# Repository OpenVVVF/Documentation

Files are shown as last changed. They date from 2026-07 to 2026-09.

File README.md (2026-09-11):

# OpenVVVF Documentation

This repository is the **single source of truth** for OpenVVVF product documentation, shared hardware data, and documentation tooling.

It is organized by hardware and software domain:

- **Control Assembly**: the reusable inverter control module (user hardware manual and software manual).
- **Power Stages**: physical chassis/inverter assemblies, each with a user manual and an assembly guide (currently documented for C2 only).
- **Safety and Compliance**: HARA, compliance mappings, and standards references; includes Testing — formal test reports and validation evidence.

Hardware designs remain in [`../InverterGen5`](../InverterGen5). Firmware and host software live in the OpenVVVF/RTE repository. This repo pulls together the documentation for all of them.

## Repository layout

```text
├── Docs/          # All documentation
├── Data/          # Shared part database and pricing data
├── Tools/         # Documentation and fabrication tooling
│   ├── BOMManager/    # Generalized BOM / fabrication package manager
│   ├── DocGen/        # Document validation and static site generator
│   └── HWRelease/     # Hardware release exporter (InverterGen5 tags -> Data/Releases)
├── Config/        # Repo-level configuration (product registry)
├── README.md
└── pyproject.toml
```

## Quick start

```bash
# Install tool dependencies
pip install -e Tools/BOMManager
pip install -e Tools/DocGen

# Run tests
pytest Tools/BOMManager/tests Tools/DocGen/tests

# Validate cross-references
python -m docgen validate

# Build the static site
python -m docgen site --output-dir site
```

## Documentation map

| Area | Path |
|---|---|
| Control assembly | `Docs/Hardware/Control-Assembly/` |
| Power stages | `Docs/Hardware/Power-Stages/` |
| Safety and compliance | `Docs/Safety-and-Compliance/` |
| Testing and validation | `Docs/Safety-and-Compliance/Testing/` |
| Part database | `Data/Parts/` |

## Contributing

See [`AGENTS.md`](AGENTS.md) and [`Docs/Agents.md`](Docs/Agents.md) for conventions used by contributors and AI agents.

## Sponsors

A special thank you to our sponsors for helping make this project possible:

<p>
  <a href="https://mouser.com">Mouser Electronics</a>
  &nbsp;&nbsp;
  <a href="https://www.mitsubishielectric.com/semiconductors/powerdevices/">Mitsubishi Electric</a>
  &nbsp;&nbsp;
  <a href="https://sendcutsend.com/">SendCutSend</a>
</p>

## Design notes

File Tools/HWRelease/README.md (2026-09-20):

# HWRelease - hardware release exporter

Turns release tags in the hardware repository (`../InverterGen5`) into
versioned, per-board artifacts under `Data/Releases/`, indexed by part number
(`HW-C2-PCB-CTRL-A`, `HW-C2-PCB-CTRL-B`, …) in `Data/Releases/manifest.json`.

## Workflow

1. In `../InverterGen5`: bump the revision in the board's KiCad files
   (`(rev "B")` in the `.kicad_sch` / `.kicad_pcb`), commit, push, and create a
   GitHub release (which creates the tag). For mechanical-only changes, instead
   rename the FreeCAD part labels and `Mechanical/Fab/<part>` folders to the
   new rev suffix and tag `<chassis-short>-<rev>` (e.g. `C2-B`): a
   chassis-named tag pins the chassis release rev and scopes the export to
   that chassis, no board rev bump needed. A release family from
   `Config/Products.yaml` (`release_families`, e.g. `C2-DCDC` = Chassis2 plus
   the DC/DC module) works the same way: tag `<family>-<rev>` (e.g.
   `C2-DCDC-A`) publishes the family's chassis tree under the family's own
   short code (`Data/Releases/C2-DCDC/A/`, `CHASSIS-C2-DCDC-A`) while boards
   keep the chassis short code (shared `HW-C2-...` part numbers).
2. Here, run:

   ```sh
   make hw-update        # or: python3 Tools/HWRelease/hwrelease.py update
   ```

   The tool fetches tags, exports each tag's `Hardware/` tree to a temp dir
   (the hardware repo's working tree is never touched), reads each board's
   revision from its KiCad files, and regenerates, via `kicad-cli` (KiCad
   flatpak), the schematic PDF, BOM CSV, gerber+drill zip, DRC report, STEP
   model, and the interactive assembly HTML (iBOM). Only board revisions not
   yet in the manifest are generated; existing ones are kept as-is.

3. Commit the new `Data/Releases/` content. The revision is now part of the
   documentation repo.

## Commands

- `hwrelease update [--tag T] [--tag-pattern GLOB] [--force] [--hw-repo PATH]`
  - export missing board revisions. Defaults: all tags, repo from
  `Config/Products.yaml` (`hardware_roots`).
- `hwrelease list` - all exported boards grouped by revision.
- `hwrelease show HW-C2-PCB-CTRL-A` - artifact paths for one part number
  (works with composite mech keys like `HW-C2-CHSP-B--C2-C` too).
- `hwrelease migrate-mech` - rebuild mech manifest entries from the exported
  `Data/Releases/<chassis>/<rev>/Mech/` trees (one entry per release; bare
  part number while unique, else `<pn>--<chassis>-<rev>`). No hardware repo
  needed.
- `hwrelease build-viewer` - regenerate `Docs/Tools/PCB-Tool/pcb-tool.html` and
  `Docs/Tools/BOM-Tool/bom-tool.html` from the manifest (runs automatically
  after `update` when new revisions were exported). docgen copies
  `Data/Releases/` into the built site.

## Vendor BOMs and pricing

`update` regenerates the chassis-level vendor BOMs (Mouser, McMaster-Carr,
SendCutSend, DigiKey, assembly, PCB) with this repo's BOMManager `generate`
against the exported tag. Board and harness BOM CSVs are first exported from
the KiCad schematics so nothing is missed. Prices come from the local price
cache / vendor APIs per your BOMManager config; variant totals (base /
standard / generous) are recorded in the manifest. If BOMManager or its deps
are unavailable, the committed BOMs from the tag are copied instead (with a
warning).

## Board ordering specs (fab_spec.yaml)

If a board directory in the hardware repo contains `fab_spec.yaml` (next to
the `.kicad_pro`), it is recorded in the manifest and shown in the tools:

```yaml
options:            # settings to pick in the JLCPCB quote form
  outer_copper: 2 oz
notes:              # free-text per-board instructions
  - "2 oz outer copper required (high-current DC bus)."
```

`Boards/fab_defaults.yaml` (same schema) holds chassis-wide notes merged into
every board (e.g. serial-number barcode instructions). The PCB Tool renders
options + notes as an "Ordering specifications" section; the BOM Tool's PCBs
table shows the per-board notes in a Notes column.

## Requirements

- KiCad via flatpak (`org.kicad.KiCad`) or `kicad-cli` on PATH.
- FreeCAD via flatpak (`org.freecad.FreeCAD`), used for mechanical-part
  extraction (optional; skipped with a warning if absent).
- `InteractiveHtmlBom` in `../InverterGen5/Hardware/BOMManager/.venv` or this
  repo's `.venv` (only needed for the interactive assembly HTML; skipped with a
  warning otherwise).

## FreeCAD extraction

On `update`, each chassis's `Mechanical/*.FCStd` is opened headlessly
(`freecadcmd` flatpak). Every `PartDesign::Body` / `App::DocumentObjectGroup`
whose **label ends with the exact part number** (`HW-...`) is exported:

- `<pn>.step`: fresh STEP, overwriting the manually exported one,
- `holes.json`: cylindrical-hole diameter histogram (mm),
- `material.json`: the part's material from the model (`ShapeMaterial` card
  name, e.g. `Aluminum-6061-T6`), when assigned; omitted when the body/group
  has no material ("Default").

The extracted material is recorded in the mech manifest entry and shown in the
BOM Tool part cards (priority: `fab_spec.yaml` material, then the extracted
material, then `info.txt` Material).

Tap/countersink diameters in `fab_spec.yaml` are validated against the model's
holes and mismatches are printed as warnings. Keep model labels exact,
e.g. `HW-C2-BSP-A`, `PhaseBusBars-HW-C2-PBB-A`.

A chassis with no boards (mechanical concept only, e.g. Chassis3) is exported
too: as long as it has a `Mechanical/*.FCStd` or a `Mechanical/Fab/` dir it
gets a `CHASSIS-<short>-<rev>` entry (rev falls back to the tag name) with its
mech parts. A chassis with no vendor BOMs and no mech parts is skipped.

## Conventions

- Board → part number mapping comes from `Config/Products.yaml` (chassis short
  codes) and `Data/Parts/Descriptors.json` (`<Chassis>|pcb|<board> → PREFIX`).
  A board missing either mapping is skipped with a warning.
- Tag naming is up to the hardware repo (e.g. `hw-rev-a`); use `--tag-pattern`
  to restrict discovery.
- `Data/Releases/` is committed generated data: do not hand-edit; regenerate
  with `--force` instead.
- **KiCad DNP grouping quirk**: KiCad marks an entire BOM `--group-by` row as
  DNP if any symbol in the group is DNP, so `export_bom` groups by
  `Value,DNP` (not `Value` alone) to keep populated rows separate. Do not
  "simplify" this back; after changing the BOM export, regenerate
  `Data/Releases/` with `hwrelease update --force`.
- **InteractiveHtmlBom DNP quirk**: CLI generation must export a KiCad XML
  netlist from the schematic, pass it through `--extra-data-file`, and select
  `--dnp-field kicad_dnp`. Without both iBOM options, DNP footprints are
  presented as ordinary placement rows and the viewer's "DNP outlined" toggle
  does nothing. The schematic is deliberately used as the same source of truth
  as the purchasing BOM; PCB DNP attributes can be stale. PCB fields are only
  used as a fallback for a board that has no matching schematic. Keep the
  regression tests in `tests/test_kicad.py` when changing the iBOM command.

## Tests

```sh
make test-hwrelease
```

## Roadmap / planned

- **Ordering screenshots per board and per part**: the user will capture
  screenshots of the JLCPCB / SendCutSend ordering flows. Convention (TBD):
  images alongside `FabSpec.md` per board (PCB Tool) and per mechanical part
  (BOM Tool / part explorer), exported into `Data/Releases/` and shown in the
  tools so ordering settings are unambiguous.
- **Mechanical parts explorer**: auto-discover mechanical parts (SendCutSend
  sheet parts, McMaster hardware) from the hardware repo at export time and
  give them their own tool page, like the PCB Tool: renders/screenshots,
  specs, vendor links, prices.

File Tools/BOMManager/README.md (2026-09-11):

# BOM Manager

Your fab-time companion for the inverter build. It aggregates the Bill of
Materials from KiCad PCB exports, wiring-harness schematics, mechanical
hardware, and custom fabricated parts, then helps you price everything,
order the right quantities (including pack sizes and what is already on your
shelf), and keep fabrication packages ready to send out.

## The interactive shell

```bash
cd Tools/BOMManager
python3 bom.py
```

```
bom> status                     # where you stand: lines, prices, attention items, fab readiness
bom> mech                       # the MechanicalBOM.txt hardware list (the tool owns this file)
bom> mech add McMaster 94669A199 12 M3x10 SHCS
bom> price 94669A199 3.10       # set a price (per piece, or per pack if packed)
bom> pack 94669A199 25          # sold in boxes of 25 -> ordering does the math
bom> stock 94669A199 19         # 19 left over on your shelf (stays local, never committed)
bom> add                        # walk through BOM lines that still need vendor PNs/prices
bom> new fab Phase Bus Bar      # scaffold a fabricated-part folder (+README)
bom> new harness GateDriverHarness
bom> new board PowerBoard
bom> rev bump DCLBB --note "widen holes"
bom> fab                        # fabrication package readiness: PCBs, fab parts, harnesses
bom> import mouser              # paste a cart/order, prices land in cache AND the committed DB
bom> import digikey ~/Downloads/digikey_bom.csv.xlsx
bom> release                    # order files + full PDF report (schematics, layers, pricing)
```

Every command also works one-shot for scripting: `python3 bom.py generate --qty 5`.
Type `help` inside the shell for the full list. **See `Docs/GUIDE.md` for the
complete usage guide.**

The old scripts (`generate_bom.py`, `manage_parts.py`, `import_*.py`) still run
; they are thin shims that delegate to the shell.

## What `generate` and `release` produce

Per chassis, under `Hardware/<Chassis>/FabricationData/`:

```text
├── BOMs/
│   ├── Consolidated_BOM.csv     # everything, with Order Qty / Pack Size / Leftover columns
│   ├── mouser_bom.csv           # upload to the vendor's BOM tool
│   ├── digikey_bom.csv
│   ├── mcmaster_bom.csv
│   ├── sendcutsend_bom.csv
│   ├── pcb_bom.csv
│   └── assembly_bom.csv         # in-house assemblies (wiring harnesses)
├── McMaster_Order_Paste.txt     # paste straight into the McMaster cart
├── PCB_Fab_Zips/<Board>.zip     # per-board fab bundles
├── Assembly/<Board>.html        # interactive assembly view per board (iBOM; via release)
├── Pricing_Report.md            # costs, pack rounding, fabrication package checklist
├── Subassembly_Pricing.json     # per-subassembly totals + lines (cost of ordering each alone; also in Builds/ and BOMs/Variants/ outputs)
├── Release_Report.pdf           # full release doc (HARA-style; via release): cover, pricing,
│                                # STEP previews, per-board 3D renders + schematic + layers
├── Builds/<variant>/            # build-variant outputs, when variants.yaml declares them
│                                # (same file set as above; the default variant stays at this root)
├── Variant_Comparison.md        # per-variant totals + part deltas (tracked)
└── variants.json                # machine-readable variant manifest (tracked)
```

Chassis with a `variants.yaml` (e.g. Chassis2's 200v/450v builds) generate all
declared build variants at once; `generate --variant 450v` builds a subset. See
[Docs/GUIDE.md](Docs/GUIDE.md#build-variants) for the schema.

## How ordering math works

- A part with `pack_size = 25` and 6 needed → order **1 pack**, 19 left over.
- `stock` counts are subtracted first: 6 needed, 19 on hand → order 0.
- Order quantities (packs) are what land in vendor CSVs and the McMaster paste
  file; lines fully covered by stock are skipped there but still shown in the
  Consolidated BOM and the report's **Pack Rounding & Stock** section.
- Prices are per **order unit**: per piece normally, per pack when packed.

## Where data lives

Committed (project data, diff-friendly):

| File | Contents |
|---|---|
| `Data/Parts/Database.json` | vendor PNs, pack sizes, manual prices, notes |
| `Data/Parts/Numbers.json` | internal PN registry with revision history |
| `Data/Parts/Descriptors.json` | short names used in part numbers |
| `Hardware/<Chassis>/Mechanical/MechanicalBOM.txt` | purchased hardware list (edit via `mech` commands) |
| `Hardware/<Chassis>/Mechanical/Fab/<Part>/` | fabricated parts: STEP + `info.txt` + image |
| `Hardware/<Chassis>/Wiring/<Name>/` | wiring harnesses: KiCad schematic + BOM CSV export |

Local only (gitignored): `Config.yaml` (API keys), `PriceCache.json`,
`Inventory.json` (your on-hand stock; your leftover screws are not project data).

## Part numbers and revisions

Every BOM line gets an internal PN like `HW-C2-BB-DCLBB-A`
(chassis, category, descriptor, revision). Registry keys are **identity-based**,
so editing a description or friendly part name never renumbers anything, and
folder names never need to change for a revision:

```text
bom> rev list
bom> rev bump DCLBB --note "widen mounting holes"
```

For fabricated parts this writes `Rev=B` into the part's `info.txt`; the
folder and STEP file stay put, so CAD and vendor links keep working.

## First-time setup

```bash
pip install -r requirements.txt        # runtime deps
pip install -r requirements-dev.txt    # + pytest, for the test suite
python3 -m pytest tests/               # sanity check
cp Config.yaml.example Config.yaml     # optional: vendor API keys (Docs/API_KEYS.md)
```

API keys are optional: the whole workflow runs on manual prices and pasted
cart/order imports.

## Docs

- `Docs/GUIDE.md`: **complete usage guide (start here)**
- `Docs/WORKFLOW.md`: end-to-end fab-time walkthrough
- `Docs/CUSTOM_PARTS.md`: fabricated parts and SendCutSend
- `Docs/PART_NUMBERING.md`: internal PN conventions and revisions
- `Docs/API_KEYS.md`: optional vendor API setup
- `Docs/SPARES_AND_REPORTING.md`: spares policies and report format

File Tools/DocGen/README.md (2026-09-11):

# docgen

OpenVVVF documentation validation and static site generator.

## Commands

```bash
# List all doc_ids
python -m docgen index

# Validate cross-references
python -m docgen validate

# Build the static HTML site
python -m docgen site --output-dir site

# Assemble a document set into a single Markdown file (legacy product-manual mode)
python -m docgen build --product <product_id> --output <file.md>

# Generate clean PDFs from the built site (run `site` first; uses headless Chromium)
python -m docgen pdf --all                    # one PDF per document
python -m docgen pdf --doc OV-C2-UM-INDEX     # a single document
python -m docgen pdf --manual OV-C2-AG-INDEX  # umbrella PDF: index document plus its chapters
python -m docgen pdf --all --chromium /path/to/chrome   # explicit Chromium/Chrome binary
```

## Document structure

Documents live under `Docs/` as `Index.md` files inside kebab-case folders. Ordered assembly chapters/steps use a `<N>_<kebab-case-title>` naming convention; the site generator renders dashes as spaces and title-cases the result.

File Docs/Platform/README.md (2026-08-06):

---
doctype: Index
doc_id: OV-PLATFORM-INDEX
title: OpenVVVF Platform Documentation
product_line: openvvvf
applies_to:
  - openvvvf-control-module
version: "0.1"
prepared: Thomas Liao
reviewed: (not yet reviewed)
date: "2026-07-30"
status: draft
---

# Platform Documentation

The control module is the reusable, application-independent part of OpenVVVF.
Documentation here applies to all power stages and application profiles.

- `Safety/` — HARA, TARA, FMEA
- `Compliance/` — Standards mapping (ISO 26262, IEC 61800-5-2, EN 5012x)
- `Architecture.md` — System architecture overview

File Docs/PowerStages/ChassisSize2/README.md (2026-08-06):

---
doctype: Index
doc_id: OV-CHASSIS-C2-INDEX
title: OpenVVVF Chassis Size 2
product_line: openvvvf
applies_to:
  - chassis-size-2
version: "0.1"
prepared: Thomas Liao
reviewed: (not yet reviewed)
date: "2026-07-30"
status: draft
normative_refs:
  - OV-UM-C2
---

# Chassis Size 2

140 V nominal / 600 A build.

- `UserManual.md` — Assembly and operating manual
- `Assembly/PowerStage/IGBTMounting.md` — IGBT module mounting procedure
- `ThermalAnalysis.md` — System thermal analysis
- `DCLinkThermal.md` — DC link standoff heat-path analysis
- `FabricationGuide.md` — Fabrication and build notes

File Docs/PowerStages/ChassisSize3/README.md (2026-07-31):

---
doctype: Index
doc_id: OV-CHASSIS-C3-INDEX
title: OpenVVVF Chassis Size 3
product_line: openvvvf
applies_to:
  - chassis-size-3
version: "0.1"
prepared: Thomas Liao
reviewed: (not yet reviewed)
date: "2026-07-30"
status: draft
---

# Chassis Size 3

Up to 1200 V / 1400 A. In development.

*Documentation will be added as the design matures.*

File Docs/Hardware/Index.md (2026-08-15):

---
doctype: Index
doc_id: OV-HW-INDEX
title: Hardware
product_line: openvvvf
applies_to:
  - openvvvf-control-module
  - chassis-size-2
version: "0.1"
date: "2026-08-08"
description: OpenVVVF hardware documentation - control module and power-stage chassis.
nav_order: 10
normative_refs:
  - OV-DOCS-INDEX
---

# Hardware

OpenVVVF hardware is split into two parts: the reusable control module and the power-stage chassis that it drives.

- [Control Assembly](Control-Assembly/Index.md) - the dual-MCU control board that runs the firmware.
- [Power Stages](Power-Stages/Index.md) - the physical inverter chassis (currently C2).

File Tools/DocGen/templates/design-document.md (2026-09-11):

---
# Template for a design analysis / calculation document.
# Place under Docs/Hardware/Power-Stages/C2/Design-Documents/<Topic>/
doctype: Design Document
doc_id: OV-C2-DD-XXXX
title: Topic Analysis
product_line: openvvvf
applies_to:
  - chassis-size-2
version: "0.1"
date: "YYYY-MM-DD"
status: draft
description: One-sentence summary of the analysis.
nav_order: 33N
normative_refs:
  - OV-C2-DD-INDEX
---

# Topic Analysis

## Purpose and scope

What question does this document answer? What is in and out of scope?

## Assumptions

- ...

## Methodology

## Calculations

## Results

## Recommendations

## References

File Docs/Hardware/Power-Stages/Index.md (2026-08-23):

---
doctype: Index
doc_id: OV-PS-INDEX
title: Power Stages
product_line: openvvvf
applies_to:
  - chassis-size-2
version: "0.4"
date: "2026-08-23"
description: Physical chassis and inverter assemblies. Each chassis family has an integration guide and an assembly guide.
nav_order: 200
---

# Power Stages

OpenVVVF power stages are physical chassis/inverter assemblies that pair with the control module. Each chassis is a family of variants built around a common form factor and IGBT module choice; the same control module can drive any of them.

## Which chassis do I have?

| Chassis | Form factor | Typical DC link | Current rating (peak phase current) | Status |
|---|---|---|---|---|
| **[C2 - Chassis Size 2](C2/Index.md)** | Mid-size | 150 / 200 / 400 V class, per DC-link capacitor selection | **465 A continuous / 600 A peak (60 s)** | Implemented, under test |

C2 ratings are stated in peak phase current (RMS equivalents: 330 A continuous, 424 A peak) per the IEC 61800-2 style 60 s overload convention: the 600 A peak is time-limited (60 s per event, windowed RMS over any 10 min ≤ 330 A RMS), and the 465 A continuous figure is a conservative analytical bound set by the DC-link electrolytic ripple rating at 6 kHz PWM. The DC-link plate temperature is an informational bound after the rev-B 6.35 mm spreader plate (≈ 90 °C conservative bound at the continuous point, at the FSR-08 90 °C derate onset; the model credits no convection). See `OV-C2-DD-THERMAL` (§6.4), `OV-C2-DD-DCLINK-RIPPLE`, and `OV-C2-DD-DCLINK-THERMAL`.

- If you are building or installing a C2 unit, start with the [C2 Integration Guide](C2/Integration-Guide/Index.md) or [C2 Assembly Guide](C2/Assembly-Guide/Index.md).

## Revision History

| Version | Date | Changes |
|---|---|---|
| 0.2 | 2026-08-15 | (Prior revision; see git history.) |
| 0.3 | 2026-08-20 | C2 current rating restated as 220 A continuous / 600 A peak (60 s, IEC 61800-2 style overload convention), replacing the previous "~600 A continuous" advertisement; continuous rating is a conservative analytical bound set by the DC-link plate temperature at 6 kHz PWM, below the ~320 A electrolytic ripple limit. References to the C2 design docs added. |
| 0.4 | 2026-08-23 | C2 re-rated per `OV-C2-DD-THERMAL` v1.3: the 600 A figure is peak phase current (424 A RMS), and the continuous rating is raised to 465 A (330 A RMS), now set by the electrolytic ripple limit; the rev-B 6.35 mm DC-link spreader plate moved the plate temperature to an informational bound below the FSR-08 derate onset. Ratings stated in peak phase current with RMS equivalents noted. |

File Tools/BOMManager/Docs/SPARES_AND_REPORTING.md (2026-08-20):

# Spares Policies and Price Reporting

## Spares Policies

Controlled by `--spares`:

| Policy | Behavior |
|---|---|
| `none` | Exact BOM quantity. |
| `cheap` | Round resistors, capacitors, and mechanical fasteners to standard pack sizes (10, 25, 50, 100, 200, 500, 1000). |
| `all` | Add `--spares-pct` percent to every line (default 10%). |

Examples:

```bash
python3 bom.py generate --spares cheap
python3 bom.py generate --spares all --spares-pct 20
```

Spares are applied to the *needed* quantity before pack-size rounding, so a
line needing 8 screws at pack size 25 with `--spares cheap` orders 1 pack
(need rounds to 10, then to 1 box of 25).

## Price Report

`Hardware/Chassis2/FabricationData/Pricing_Report.md` is regenerated on every run and contains:

- One section per vendor with line items, order info, unit price, line total, and price source.
- Vendor subtotals.
- Grand total for the requested quantity.
- A quantity-scaling table (default 3, 5, 10, 25 units).
- A **Pack Rounding & Stock** section: need vs. on-hand vs. packs ordered vs. leftover.
- A **Fabrication Package** checklist: per-board fab files/zip/price, per-part STEP/info/price/rev, harness CSVs, and anything not ready.
- A list of parts with unknown/missing prices.
- A SendCutSend details section with material, thickness, finish, STEP path, and embedded `info.png` images.

The report is Markdown so it renders nicely in GitHub/GitLab and can be committed to track project cost over time. Each chassis gets its own report under `Hardware/<Chassis>/FabricationData/`.

## Quantity Scaling

Use `--qty N` to scale the whole BOM:

```bash
python3 bom.py generate --qty 5
```

The consolidated CSV quantities are multiplied by N (order quantities are
computed from the scaled need), and the report grand total reflects N units.
You can change the scaling table with `--extra-qtys`:

```bash
python3 bom.py generate --qty 1 --extra-qtys 2,5,10,25,50
```

## Price Sources

Each line shows where the price came from:

- `mouser_api`, `digikey_api`, `octopart_api`: live lookup (needs API keys).
- `mouser_cart_import`, `mcmaster_order_import`, `jlcpcb_order_import`: pasted cart/order imports.
- `sendcutsend_folder`: the part's `info.txt`.
- `manual`: set by hand in the shell (`price`, `pack`, `fab pcb-price`).
- `cache`: from `PriceCache.json`.
- `unknown`: no price found; listed in the report for follow-up.

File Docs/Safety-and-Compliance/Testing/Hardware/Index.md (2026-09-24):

---
doctype: Index
doc_id: OV-TEST-HW-INDEX
title: Hardware Tests
product_line: openvvvf
applies_to:
  - openvvvf-control-module
  - chassis-size-2
version: "0.4"
date: "2026-09-24"
description: Hardware test reports and validation evidence.
nav_order: 341
---

# Hardware Tests

Electrical, thermal, mechanical, and environmental test records.

## PMSM motor

- [PMSM Resistance Calibration Validation](PMSM-Motor-Calibration/Resistance/Index.md)
- [Power Resistor Sanity Check](PMSM-Motor-Calibration/Resistor-Sanity-Check/Index.md)
- [PMSM Inductance Calibration Validation](PMSM-Motor-Calibration/Inductance/Index.md)

## Induction motor

- [Induction Motor Testbed](Induction-Motor-Calibration/Testbed/Index.md)
- [Induction Motor Resistance Calibration Validation](Induction-Motor-Calibration/Resistance/Index.md)
- [Inductance Calibration Validation](Induction-Motor-Calibration/Inductance/Index.md)
- [Induction Motor 1-Hour No-Load Test](Induction-Motor-No-Load-Test/Index.md)
- [Induction Motor 180 V Power Stage Bring-up](Induction-Motor-180V-Bringup/Index.md)
- [Induction Motor 180 V 20-Minute Reversal Test](Induction-Motor-180V-Reversal/Index.md)

## Gen7 hardware

- [Gen7 Board Temperature Sensor Validation](Gen7-Temp-Sensor-Validation/Index.md) - first Gen7 test record; validates the three board NTC temperature channels against a thermal imager under a torch-applied gradient.
- [Low-Power Regen 100 A Phase-Current Endurance (No Cooling)](Low-Power-Regen-100A-No-Cooling/Index.md) - 22-minute continuous regen at −100 A q-axis current on a dynamometer-spun induction machine with the bare power stage (no heatsink, no fan); peak board temp 80.4 °C.
- [200 A Regen to 79 °C — Gen7 Size 2](Low-Power-Regen-200A-Gen7-Size2/Index.md) - 200 A q-axis regen staircase on Gen7 size 2, 3.14 kW average returned to the DC link, split at the first 79 °C inverter NTC reading; heatsink fitted without thermal interface material.
- [Thermal OTP Trip — 200 A Regen, Gen7 Size 2](Thermal-OTP-200A-Gen7-Size2/Index.md) - continuation of the same recording past 79 °C through the intended thermal over-temperature protection trip and cooldown.
- [Initial 400 A Regen Test — Gen7 Size 2](Low-Power-Regen-400A-Gen7-Size2/Index.md) - first 400 A q-axis regen run with a Chroma load bank clamping the bus at 150 V (Sorensen regen sink ~50 A); 8.78 kW peak; apparent phase-current spikes later attributed to 150 A-rated Tektronix current clamps saturating (measurement artifact).
- [450 A / 13 kW Regen — Gen7 Size 2](Low-Power-Regen-450A-Gen7-Size2/Index.md) - 450 A q-axis regen at 2,000 RPM shaft speed, 12.8 kW average returned to the DC link, sustained 78 s until the inverter overtemperature protection tripped at ~80 °C baseplate as designed.
- [200 A Regen Steady-State Thermal Test — Gen7 Size 2](Low-Power-Regen-200A-Steady-State-Gen7-Size2/Index.md) - 54.7-minute continuous 200 A regen on the thermally-pasted assembly; baseplate plateaued at 44.4 / 44.0 °C against 22.5 °C ambient, validating the interface rework.
- [200 A Motoring Steady-State Thermal Test — Gen7 Size 2](Low-Power-Motoring-200A-Steady-State-Gen7-Size2/Index.md) - motoring-direction counterpart: 42-minute 200 A positive-torque hold drawing 2.46 kW, baseplate plateau 43.6 / 43.5 °C in cooler night ambient — same rise over ambient as regen, completing bidirectional 200 A continuous-duty validation.
- [300 A Regen Steady-State Thermal Test — Gen7 Size 2](Low-Power-Regen-300A-Steady-State-Gen7-Size2/Index.md) - 22.9-minute continuous 300 A regen at ~2,600 RPM returning 11.7 kW to a 150 V-clamped bus; baseplate reached effective steady state at 63.2 / 61.7 °C (~39 K over ambient). Stopped because the Zero ZF75-10 machine hit 86 °C on the thermal imager, not due to any inverter limit or fault.

## Cross-cutting

- [Motor Self-Commissioning Accuracy Report](Motor-Self-Commissioning-Accuracy/Index.md) - aggregates the calibration-validation measurements into a single accuracy record for the self-commissioning routine.

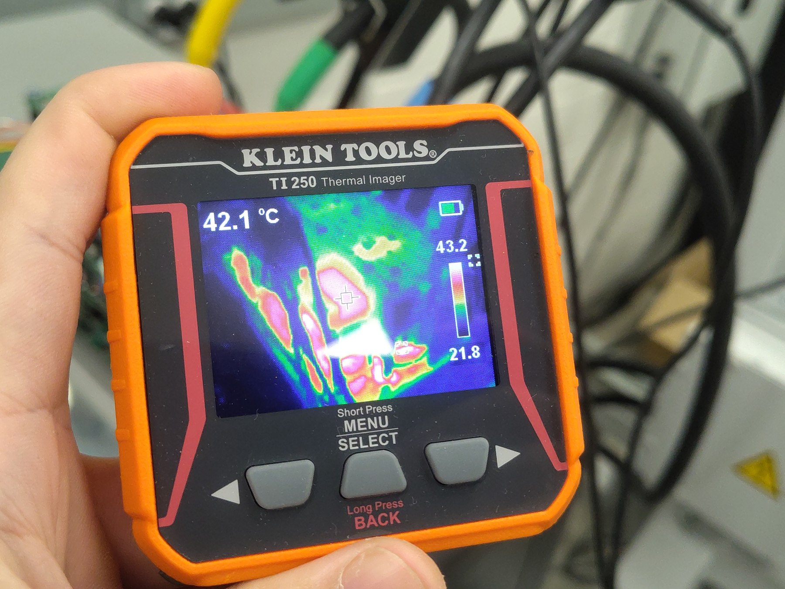
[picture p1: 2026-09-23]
Docs/Safety-and-Compliance/Testing/Hardware/Low-Power-Regen-200A-Gen7-Size2/Thermal-01.jpg

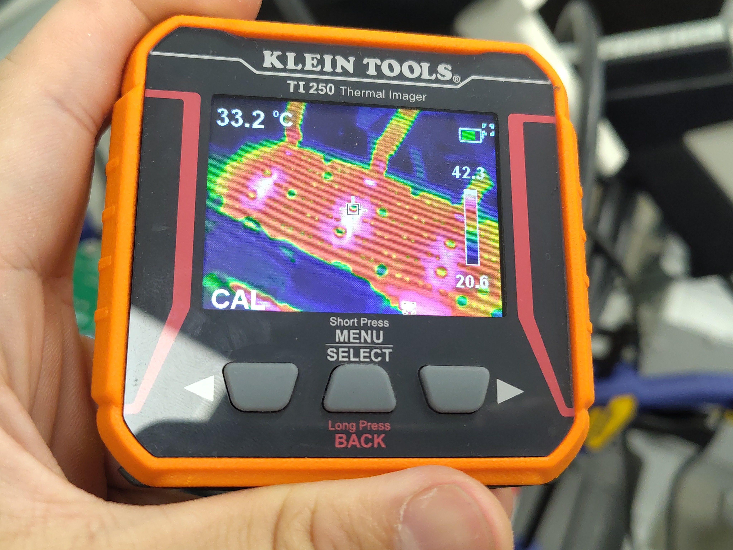
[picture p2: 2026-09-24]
Docs/Safety-and-Compliance/Testing/Hardware/Low-Power-Motoring-200A-Steady-State-Gen7-Size2/Thermal-02-Original.jpg

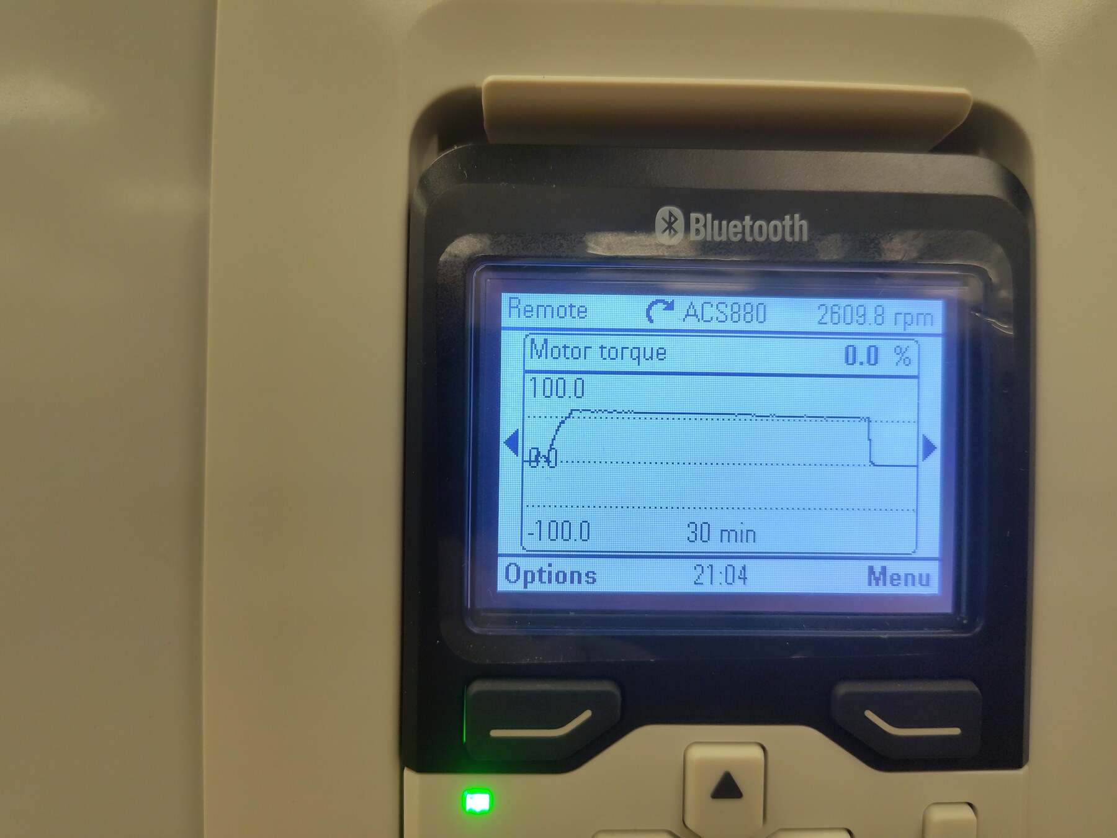
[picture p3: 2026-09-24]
Docs/Safety-and-Compliance/Testing/Hardware/Low-Power-Regen-300A-Steady-State-Gen7-Size2/Dyno-Display.jpg

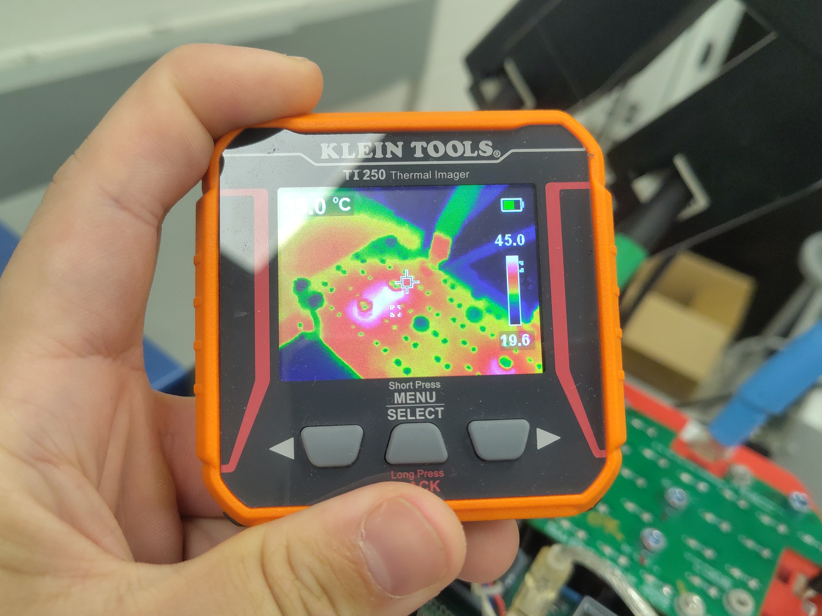
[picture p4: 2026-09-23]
Docs/Safety-and-Compliance/Testing/Hardware/Low-Power-Regen-200A-Gen7-Size2/Thermal-04-Original.jpg

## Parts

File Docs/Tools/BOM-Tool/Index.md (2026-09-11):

---
doctype: Tool Manual
doc_id: OV-TOOLS-BOM-TOOL
title: BOM Tool
product_line: openvvvf
applies_to:
  - openvvvf-control-module
  - chassis-size-2
version: "0.4"
date: "2026-09-10"
description: Vendor order BOMs (Mouser, McMaster-Carr, SendCutSend, PCB, 3D Printed; DigiKey when data exists) per chassis, revision, and build variant.
nav_order: 603
normative_refs:
  - OV-TOOLS-INDEX
---

# BOM Tool

The BOM Tool serves the per-chassis vendor order BOMs exported from the hardware repository's release tags. Select a chassis, revision, and build variant, then preview or download the vendor BOM you need.

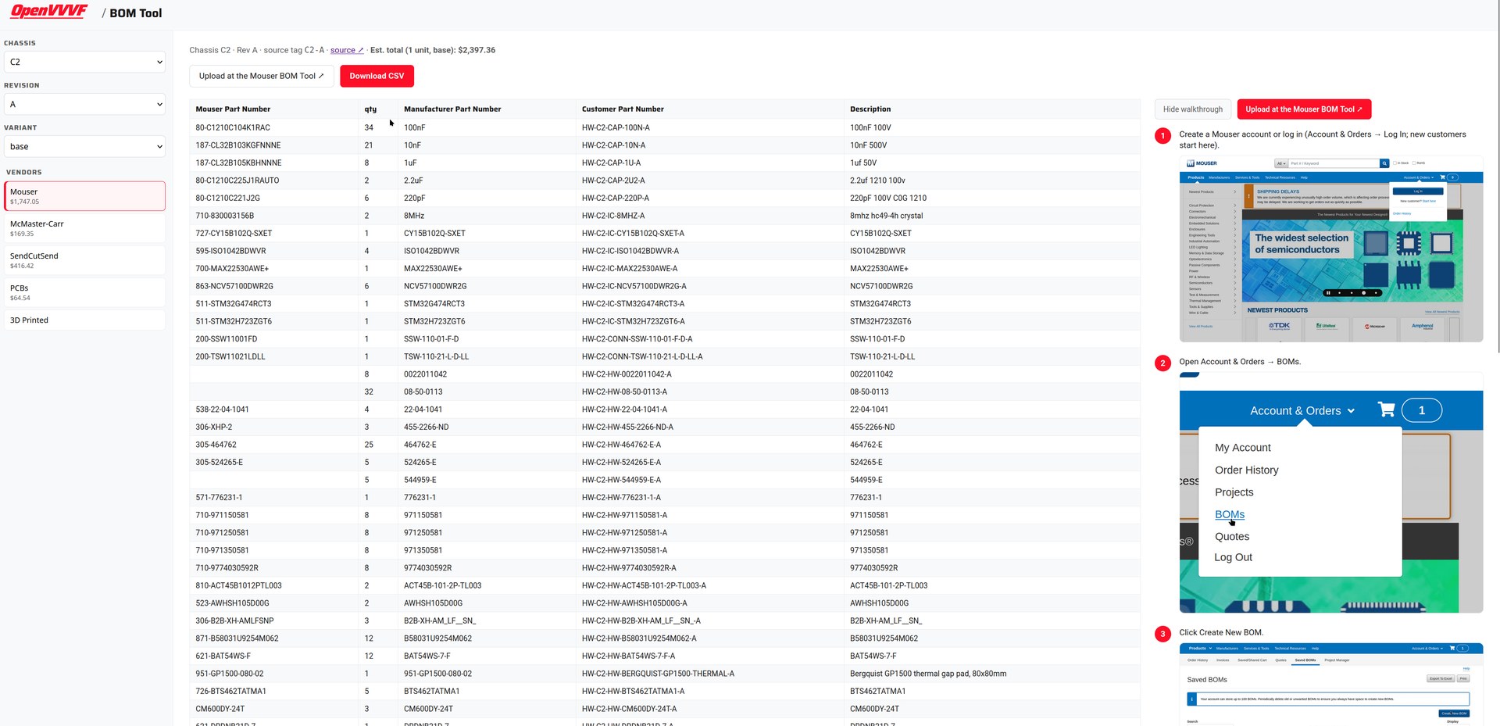
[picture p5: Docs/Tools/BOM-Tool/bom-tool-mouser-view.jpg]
BOM Tool showing the Mouser order BOM with the ordering walkthrough


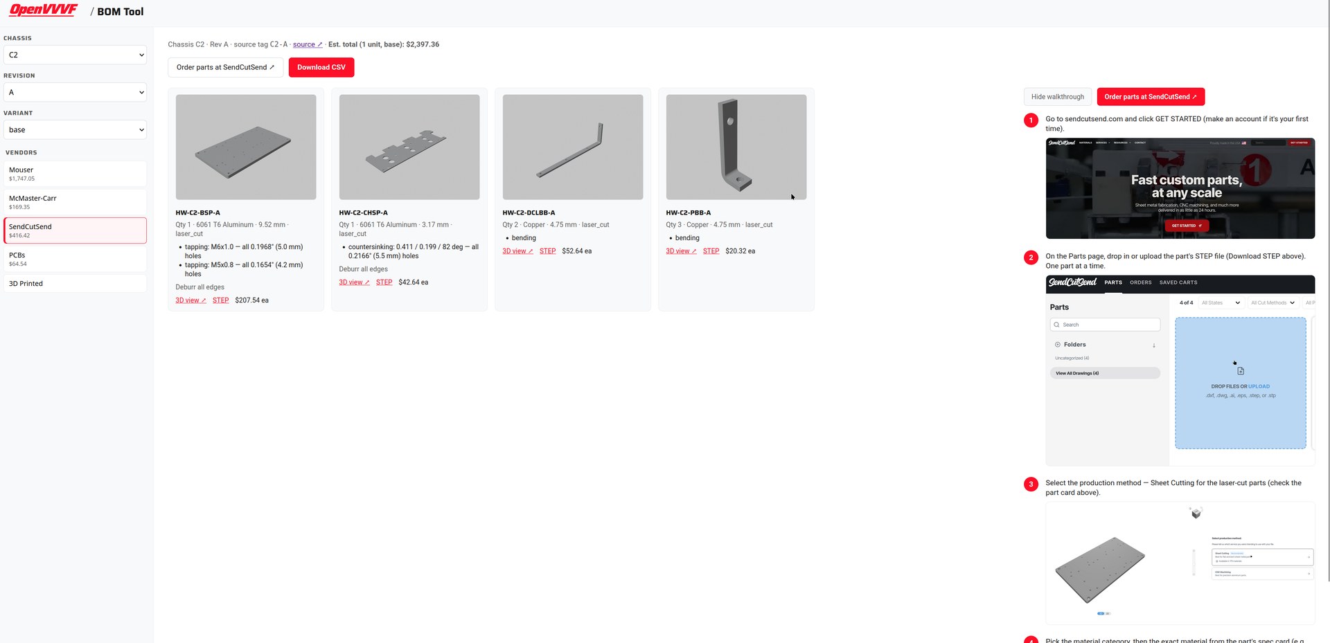
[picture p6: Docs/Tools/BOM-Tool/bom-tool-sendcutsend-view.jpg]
BOM Tool showing fabricated parts with 3D previews and SendCutSend ordering


## Using the tool

1. Open the [BOM Tool](bom-tool.html).
2. Choose the **chassis**, **revision**, and **variant** (`base` is the standard build; named variants such as `generous` come from the hardware repo's BOM variants).
3. Click a vendor button (**Mouser**, **McMaster-Carr**, **SendCutSend**, **PCBs** (JLCPCB fab), **3D Printed** (printed parts); a **DigiKey** button appears only when DigiKey data exists for that release) to preview the BOM inline. Vendor buttons show their share of the cost estimate. The consolidated and assembly (in-house harnesses) BOMs have no buttons; download their CSVs from the release's `BOMs/` directory.
4. Order with as few clicks as vendors allow. For the selected chassis+revision the actions row may show **ready-made shared carts** ("Open ready-made Mouser/SendCutSend cart", "Open shared DigiKey list" — buy as-is). For Mouser, **Copy order list** copies `Mouser PN<tab>qty` lines and opens the BOM import; paste there (Account & Orders → Import). For McMaster-Carr, **Copy order paste** copies `PN,qty` lines for the order pad, and **Open McMaster-Carr order page** jumps straight to it. The subassembly view (step 5) has equivalent copy buttons limited to that subassembly's lines; entries without a vendor part number are skipped.
5. To price one part of the inverter on its own (e.g. just the control board or the wiring harnesses), pick it in the **Subassembly** selector between the variant selector and the vendor buttons. The preview then shows that subassembly's lines with per-vendor subtotals instead of a vendor table. These totals assume you order *only* that subassembly — pack sizes are rounded up separately per subassembly, so the subassemblies can add up to more than the whole-BOM estimate. Clicking a vendor returns to the whole-BOM view. Releases exported before this feature have no per-subassembly data yet; the selector shows a disabled "All (no per-subassembly data yet)" entry until the next `hwrelease update`.
6. Use **Download CSV** to save it for ordering (e.g. pasting into the vendor's BOM import). For boards, **View boards in PCB Tool** takes you to the per-board gerbers/specs, and **Order PCBs at JLCPCB** opens the fab.

### Ordering walkthrough screenshots

When a vendor is selected, the tool shows a step-by-step walkthrough of that vendor's upload/ordering flow below the buttons (for McMaster-Carr there's also a button that copies the order paste to the clipboard). The walkthrough is hand-maintained: drop files next to this document named `ordering-<vendor>-<n>.png` (screenshot) and `ordering-<vendor>-<n>.txt` (one-line caption), numbered in order (`n` = 1, 2, …; vendors: `mouser`, `digikey`, `mcmaster`, `sendcutsend`, `jlc`). Either file may exist alone: steps without a screenshot show as text only. No regeneration is needed; they are picked up on the next site build.

The estimate in the header reflects the selected variant (`base`, `standard`, `generous`).

### Registering ready-made shared carts (maintainer)

None of the vendors offer anonymous cart URLs, so shared carts are created once by the maintainer in their vendor account and registered in `shared-carts.json`, a hand-edited file next to this page (it is not generated; `hwrelease build-viewer` never touches it):

```json
{ "C2": { "C": { "mouser": "https://...", "sendcutsend": "https://...", "digikey": "https://..." } } }
```

Keys are `"<chassis-short>"` → `"<rev>"` → vendor → URL; vendors without an entry simply show no button, and a missing `shared-carts.json` is fine.

- **Mouser**: build the BOM in a My Mouser project (Project Manager), use Share, and copy the `ProjectDetail.aspx?AccessID=…` link. Visitors open it and click "Order Project" — this keeps project ownership/annotations with the maintainer.
- **SendCutSend**: load a saved cart, use the cart's share link (`https://cart.sendcutsend.com/<id>`). Caveats: links expire after ~30 days (or on cart/account changes), and CNC-machined parts can't be shared.
- **DigiKey**: share a list from the DigiKey lists page. (Not currently used — this project's BOMs carry almost no DigiKey part numbers.)

## Where the data comes from

The CSVs are regenerated from the tag's KiCad sources on every export: HWRelease (`make hw-update`) runs BOMManager's `generate` (with pricing) against the exported tag tree, so they can never go stale. They live in `Data/Releases/<chassis>/<rev>/BOMs/` and are indexed in `Data/Releases/manifest.json` under `CHASSIS-<chassis>-<rev>` entries. The page itself is regenerated with `hwrelease build-viewer` (runs automatically after `update`).

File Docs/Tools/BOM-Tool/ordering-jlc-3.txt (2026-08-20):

JLCPCB auto-detects the layers and dimensions. Set the remaining options from the board's ordering specs (Notes column / PCB Tool), e.g. 2 oz copper for DCBusCapacitorBoard.

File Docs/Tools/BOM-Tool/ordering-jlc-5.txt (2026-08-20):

Always: select 2D barcode Only, size 10*10mm, choose Specify Position, then Submit. Never leave the position up to the fab.

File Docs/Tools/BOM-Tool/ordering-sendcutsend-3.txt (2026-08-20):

Select the production method: Sheet Cutting for the laser-cut parts (check the part card above).

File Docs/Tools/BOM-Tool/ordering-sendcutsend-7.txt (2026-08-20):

For Tapping: SendCutSend lists every hole diameter: select the thread from the part's fab spec for each diameter that needs it, leave the rest unselected.

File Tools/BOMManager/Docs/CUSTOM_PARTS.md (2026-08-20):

# Custom Parts (McMaster-Carr and SendCutSend)

## McMaster-Carr Parts

McMaster-Carr has an approved-customer Product Information API (see
`API_KEYS.md`). If you configure the certificate-based credentials, the tool
uses the official API; otherwise it falls back to cached or manually set
prices.

### The mechanical list

`Hardware/<Chassis>/Mechanical/MechanicalBOM.txt` is owned by the tool; add
and change rows from the shell instead of editing by hand:

```text
bom> mech                                   # list with prices
bom> mech add McMaster 94669A199 12 M3x10 SHCS
bom> mech set 94669A199 20
bom> mech rm 94669A199
```

The file stays a plain CSV (`Qty,Vendor,PN,Description`), sorted and
deduplicated on every change. Any vendor string works (`McMaster`, `Digikey`,
`Mitsubishi`, ...). Set prices with `price <pn> <usd>`, and if the part comes
in a box, `pack <pn> 25 <box price>`; ordering then counts packs, not pieces.

## SendCutSend Fabricated Parts

Bus bars, plates, brackets, and other laser/waterjet-cut parts live one folder
per part under `Hardware/<Chassis>/Mechanical/Fab/<PartName>/`. Scaffold a new
one from the shell:

```text
bom> new fab DC Link Bus Bar
```

which creates:

```text
Hardware/<Chassis>/Mechanical/Fab/HW-C2-DCLBB-A/
├── info.txt        # specs and price (template)
└── README.md       # what goes here
```

Drop in `<folder>.step` (required) and `info.png` (optional, embedded in the
price report).

### `info.txt` fields

```ini
PartName=DC Link Bus Bar
Material=Copper
Thickness_mm=4.75
Qty=2
Dimensions_in=12.357x0.551 in
Finish=Bending
UnitPrice=50.71
Process=Sheet Cutting
Notes=Tin plate ends after forming
```

| Field | Description |
|---|---|
| PartName | Human-readable name. Words like "bus bar", "plate", "bracket" drive category detection. |
| Material | e.g., `Copper`, `5052 aluminum` |
| Thickness_mm | Sheet thickness in mm |
| Qty | Quantity per chassis |
| Dimensions_in or Dimensions_mm | Part dimensions |
| Finish | e.g., `as cut`, `Bending`, `tinned`, `anodized` |
| UnitPrice | USD per part |
| Process | e.g., `Sheet Cutting` |
| Notes | Design notes, tolerances, etc. |
| Rev | Managed by the tool (`rev bump`); do not edit by hand. |

Each part gets an internal part number such as `HW-C2-BB-DCLBB-A`
(see `PART_NUMBERING.md`).

### Importing from a SendCutSend cart

After building a cart on SendCutSend, copy the page text and paste it:

```text
bom> import sendcutsend            # paste, then Ctrl+D
bom> import sendcutsend cart.txt   # or from a file
bom> import sendcutsend cart.txt --dry-run
```

The importer matches cart filenames to existing folders regardless of token
order (`C2_HW_BSP_A.step` matches `HW-C2-BSP-A`), creates missing folders, and
writes/updates each `info.txt`, including the quoted price.

### Revisions

`rev bump DCLBB --note "..."` bumps the revision and writes `Rev=` into
`info.txt`. Folders and STEP files are never renamed, so vendor re-uploads and
CAD links keep working.

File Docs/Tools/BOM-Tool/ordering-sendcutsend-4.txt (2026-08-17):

Pick the material category, then the exact material from the part's spec card (e.g. Copper, 6061 T6 Aluminum).

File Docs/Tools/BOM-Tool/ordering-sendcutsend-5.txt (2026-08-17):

Pick the thickness from the part's spec card (e.g. .187" / 4.7 mm for the bus bars).

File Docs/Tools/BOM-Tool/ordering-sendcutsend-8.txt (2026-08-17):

Same for Countersinking: pick the feature per hole diameter per the spec, then review the quote and add to cart. Repeat for each part.

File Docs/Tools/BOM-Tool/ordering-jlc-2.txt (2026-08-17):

Click Add gerber file and upload the board's gerber zip (Download zip in the table above).

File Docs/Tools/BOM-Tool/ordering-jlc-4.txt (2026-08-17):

Under Mark on PCB, choose 2D barcode (Serial Number).

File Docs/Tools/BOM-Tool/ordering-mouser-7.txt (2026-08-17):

Set the options (BOM name, currency, RoHS filter) and click Process BOM.

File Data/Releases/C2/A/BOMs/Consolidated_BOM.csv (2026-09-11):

Quantity | Order Qty | Pack Size | Leftover | Internal P/N | Description | Customer Part No. | Manufacturer Part No. | Vendor | Vendor P/N
6 | 6 |  |  | HW-C2-3DP-DCLSPCR-PRINTED-A | HW-C2-DCLSPCR-PRINTED-A |  | HW-C2-DCLSPCR-PRINTED-A | sendcutsend | HW-C2-DCLSPCR-PRINTED-A
1 | 1 |  |  | HW-C2-3DP-SHELL-PRINTED-A | HW-C2-SHELL-PRINTED-A |  | HW-C2-SHELL-PRINTED-A | sendcutsend | HW-C2-SHELL-PRINTED-A
2 | 2 |  |  | HW-C2-BB-DCLBB-A | HW-C2-DCLBB-A |  | HW-C2-DCLBB-A | sendcutsend | HW-C2-DCLBB-A
3 | 3 |  |  | HW-C2-BB-PBB-A | HW-C2-PBB-A |  | HW-C2-PBB-A | sendcutsend | HW-C2-PBB-A
70 | 70 |  |  | HW-C2-CAP-100N-A | 100nF 100V | CBPN-JMGYO-100nF | 100nF | mouser | 80-C1210C104K1RAC
21 | 21 |  |  | HW-C2-CAP-10N-A | 10nF 500V | CBPN-FZHK8-10nF | 10nF | mouser | 187-CL32B103KGFNNNE
37 | 37 |  |  | HW-C2-CAP-10U-A | 10uF 25V | CBPN-Z2OBH-10uF | 10uF | mouser | 187-CL32A106KAULNNE
8 | 8 |  |  | HW-C2-CAP-1U-A | 1uf 50V | CBPN-6J4DK-1uf | 1uF | mouser | 187-CL32B105KBHNNNE
2 | 2 |  |  | HW-C2-CAP-2U2-A | 2.2uf 1210 100v | CBPN-X4VU0-22uf | 2.2uF | mouser | 80-C1210C225J1RAUTO
6 | 6 |  |  | HW-C2-CAP-220P-A | 220pF 100V C0G 1210 |  | 220pF | mouser | 80-C1210C221J2G
4 | 4 |  |  | HW-C2-CAP-22P-A | 22pF 50V | CBPN-XGV7B-22pF | 22pF | mouser | 80-C1210C220J5G
2 | 2 |  |  | HW-C2-IC-8MHZ-A | 8mhz hc49-4h crystal | CBPN-QQUPE-8mhz | 8MHz | mouser | 710-830003156B
1 | 1 |  |  | HW-C2-IC-CY15B102Q-SXET-A | CY15B102Q-SXET |  | CY15B102Q-SXET | mouser | 727-CY15B102Q-SXET
4 | 4 |  |  | HW-C2-IC-ISO1042BDWVR-A | ISO1042BDWVR |  | ISO1042BDWVR | mouser | 595-ISO1042BDWVR
1 | 1 |  |  | HW-C2-IC-ISO1212DBQ-A | ISO1212DBQ |  | ISO1212DBQ | mouser | 595-ISO1212DBQ
1 | 1 |  |  | HW-C2-IC-MAX22530AWE-A | MAX22530AWE+ |  | MAX22530AWE+ | mouser | 700-MAX22530AWE+
6 | 6 |  |  | HW-C2-IC-NCV57100DWR2G-A | NCV57100DWR2G |  | NCV57100DWR2G | mouser | 863-NCV57100DWR2G
1 | 1 |  |  | HW-C2-IC-STM32G474RCT3-A | STM32G474RCT3 |  | STM32G474RCT3 | mouser | 511-STM32G474RCT3
1 | 1 |  |  | HW-C2-IC-STM32H723ZGT6-A | STM32H723ZGT6 |  | STM32H723ZGT6 | mouser | 511-STM32H723ZGT6
1 | 1 |  |  | HW-C2-CONN-SSW-110-01-F-D-A | SSW-110-01-F-D |  | SSW-110-01-F-D | mouser | 200-SSW11001FD
1 | 1 |  |  | HW-C2-CONN-TSW-110-21-L-D-LL-A | TSW-110-21-L-D-LL |  | TSW-110-21-L-D-LL | mouser | 200-TSW11021LDLL
1 | 1 |  |  | HW-C2-MECH-1821A55-A | 1821A55 |  | 1821A55 | mcmaster | 1821A55
8 | 8 |  |  | HW-C2-MECH-6926K352-A | 6926K352 |  | 6926K352 | mcmaster | 6926K352
5 | 5 |  |  | HW-C2-MECH-6926K56-A | 6926K56 |  | 6926K56 | mcmaster | 6926K56
1 | 1 |  |  | HW-C2-MECH-7381K23-A | 7381K23 |  | 7381K23 | mcmaster | 7381K23
8 | 1 | 100 | 92 | HW-C2-MECH-90128A232-A | 90128A232 |  | 90128A232 | mcmaster | 90128A232
5 | 1 | 50 | 45 | HW-C2-MECH-90225A102-A | 90225A102 |  | 90225A102 | mcmaster | 90225A102
4 | 4 |  |  | HW-C2-MECH-91292A108-A | 91292A108 |  | 91292A108 | mcmaster | 91292A108
18 | 1 | 50 | 32 | HW-C2-MECH-91292A134-A | 91292A134 |  | 91292A134 | mcmaster | 91292A134
4 | 1 | 50 | 46 | HW-C2-MECH-91294A220-A | 91294A220 |  | 91294A220 | mcmaster | 91294A220
1 | 1 |  |  | HW-C2-MECH-91458A112-A | 91458A112 |  | 91458A112 | mcmaster | 91458A112
6 | 1 | 25 | 19 | HW-C2-MECH-91502A180-A | 91502A180 |  | 91502A180 | mcmaster | 91502A180
6 | 1 | 10 | 4 | HW-C2-MECH-91502A183-A | 91502A183 |  | 91502A183 | mcmaster | 91502A183
4 | 4 |  |  | HW-C2-MECH-94180A351-A | 94180A351 |  | 94180A351 | mcmaster | 94180A351
6 | 6 |  |  | HW-C2-MECH-94669A190-A | 94669A190 |  | 94669A190 | mcmaster | 94669A190
6 | 6 |  |  | HW-C2-MECH-94669A196-A | 94669A196 |  | 94669A196 | mcmaster | 94669A196
12 | 12 |  |  | HW-C2-MECH-94669A199-A | 94669A199 |  | 94669A199 | mcmaster | 94669A199
2 | 2 |  |  | HW-C2-MECH-94669A202-A | 94669A202 |  | 94669A202 | mcmaster | 94669A202
12 | 12 |  |  | HW-C2-MECH-96738A257-A | 96738A257 |  | 96738A257 | mcmaster | 96738A257
25 | 1 | 25 | 0 | HW-C2-MECH-98044A224-A | 98044A224 |  | 98044A224 | mcmaster | 98044A224
8 | 8 |  |  | HW-C2-HW-0022011042-A | 0022011042 |  | 0022011042 | mouser
32 | 32 |  |  | HW-C2-HW-08-50-0113-A | 08-50-0113 |  | 08-50-0113 | mouser
4 | 4 |  |  | HW-C2-HW-22-04-1041-A | 22-04-1041 |  | 22-04-1041 | mouser | 538-22-04-1041
3 | 3 |  |  | HW-C2-HW-455-2266-ND-A | 455-2266-ND |  | 455-2266-ND | mouser | 306-XHP-2
25 | 25 |  |  | HW-C2-HW-464762-E-A | 464762-E |  | 464762-E | mouser | 305-464762
5 | 5 |  |  | HW-C2-HW-524265-E-A | 524265-E |  | 524265-E | mouser | 305-524265-E
5 | 5 |  |  | HW-C2-HW-544959-E-A | 544959-E |  | 544959-E | mouser
1 | 1 |  |  | HW-C2-HW-776231-1-A | 776231-1 |  | 776231-1 | mouser | 571-776231-1
8 | 8 |  |  | HW-C2-HW-971150581-A | 971150581 |  | 971150581 | mouser | 710-971150581
8 | 8 |  |  | HW-C2-HW-971250581-A | 971250581 |  | 971250581 | mouser | 710-971250581
8 | 8 |  |  | HW-C2-HW-971350581-A | 971350581 |  | 971350581 | mouser | 710-971350581
8 | 8 |  |  | HW-C2-HW-9774030592R-A | 9774030592R |  | 9774030592R | mouser | 710-9774030592R
2 | 2 |  |  | HW-C2-HW-ACT45B-101-2P-TL003-A | ACT45B-101-2P-TL003 |  | ACT45B-101-2P-TL003 | mouser | 810-ACT45B1012PTL003
2 | 2 |  |  | HW-C2-HW-AWHSH105D00G-A | AWHSH105D00G |  | AWHSH105D00G | mouser | 523-AWHSH105D00G
3 | 3 |  |  | HW-C2-HW-B2B-XH-AM_LF__SN_-A | B2B-XH-AM_LF__SN_ |  | B2B-XH-AM_LF__SN_ | mouser | 306-B2B-XH-AMLFSNP
12 | 12 |  |  | HW-C2-HW-B58031U9254M062-A | B58031U9254M062 |  | B58031U9254M062 | mouser | 871-B58031U9254M062
12 | 12 |  |  | HW-C2-HW-BAT54WS-7-F-A | BAT54WS-7-F |  | BAT54WS-7-F | mouser | 621-BAT54WS-F
1 | 1 |  |  | HW-C2-HW-BERGQUIST-GP1500-THERMAL-A | Bergquist GP1500 thermal gap pad, 80x80mm |  | 951-GP1500-080-02 | mouser | 951-GP1500-080-02
5 | 5 |  |  | HW-C2-HW-BTS462TATMA1-A | BTS462TATMA1 |  | BTS462TATMA1 | mouser | 726-BTS462TATMA1
3 | 3 |  |  | HW-C2-HW-CM600DY-24T-A | CM600DY-24T |  | CM600DY-24T | mouser | CM600DY-24T
1 | 1 |  |  | HW-C2-HW-DC-LINK-MODULE-HOLDER-A | DC Link Module Holder - 200V Class |  | DC Link Module Holder - 200V Class | sendcutsend | DC Link Module Holder - 200V Class
1 | 1 |  |  | HW-C2-HW-DRDNB21D-7-A | DRDNB21D-7 |  | DRDNB21D-7 | mouser | 621-DRDNB21D-7
1 | 1 |  |  | HW-C2-HW-EC7BW-110S12-A | EC7BW-110S12 |  | EC7BW-110S12 | mouser | 418-EC7BW-110S12
12 | 12 |  |  | HW-C2-HW-FDFNYD1-110-5-A | FDFNYD1-110(5) |  | FDFNYD1-110(5) | mouser | 161-FDFNYD1-1105
4 | 4 |  |  | HW-C2-HW-LA37S600S05KM-A | LA37S600S05KM |  | LA37S600S05KM | mouser | 838-LA37S600S05KM
1 | 1 |  |  | HW-C2-HW-LT3080IQ-PBF-A | LT3080IQ#PBF |  | LT3080IQ#PBF | mouser | 584-LT3080IQ#PBF
2 | 2 |  |  | HW-C2-HW-LTST-C230CKT-A | LTST-C230CKT |  | LTST-C230CKT | mouser | 859-LTST-C230CKT
2 | 2 |  |  | HW-C2-HW-LTST-C230GKT-A | LTST-C230GKT |  | LTST-C230GKT | mouser | 859-LTST-C230GKT
1 | 1 |  |  | HW-C2-HW-MF-RHT200_32-2-A | MF-RHT200_32-2 |  | MF-RHT200_32-2 | mouser | 652-MF-RHT200/32-2
6 | 6 |  |  | HW-C2-HW-MGJ2D121509MPC-R7-A | MGJ2D121509MPC-R7 |  | MGJ2D121509MPC-R7 | mouser | 580-MGJ2D121509MPCR7
6 | 6 |  |  | HW-C2-HW-MKP1848S61010JY5B-A | MKP1848S61010JY5B |  | MKP1848S61010JY5B | mouser | 75-MKP1848S61010JY5B
5 | 5 |  |  | HW-C2-HW-MM3Z3V0ST1G-A | MM3Z3V0ST1G |  | MM3Z3V0ST1G | mouser | 863-MM3Z3V0ST1G
1 | 1 |  |  | HW-C2-HW-NXFT15XH103FEAB021-A | NXFT15XH103FEAB021 |  | NXFT15XH103FEAB021 | mouser | 81-NXFT15XH103FEAB21
1 | 1 |  |  | HW-C2-HW-RD7-12S033R-A | RD7-12S033R |  | RD7-12S033R | mouser | 737-RD7-12S033R
3 | 3 |  |  | HW-C2-HW-RKE-1205S_H-A | RKE-1205S_H |  | RKE-1205S_H | mouser | 919-RKE-1205S/H
2 | 2 |  |  | HW-C2-HW-RTS103C1R2M6L201-A | RTS103C1R2M6L201 |  | RTS103C1R2M6L201 | mouser | 527-RTS103C1R2M6L201
2 | 2 |  |  | HW-C2-HW-S3N-A | S3N |  | S3N | mouser | 512-S3N
2 | 2 |  |  | HW-C2-HW-SSW-103-01-L-D-A | SSW-103-01-L-D |  | SSW-103-01-L-D | mouser | 200-SSW10301LD
1 | 1 |  |  | HW-C2-HW-SSW-104-01-L-D-A | SSW-104-01-L-D |  | SSW-104-01-L-D | mouser | 200-SSW10401LD
2 | 2 |  |  | HW-C2-HW-SSW-108-01-L-D-A | SSW-108-01-L-D |  | SSW-108-01-L-D | mouser | 200-SSW10801LD
1 | 1 |  |  | HW-C2-HW-SSW-110-01-F-D-A | SSW-110-01-F-D |  | SSW-110-01-F-D | mouser
1 | 1 |  |  | HW-C2-HW-STS41A-AWLB-R3-A | STS41A-AWLB-R3 |  | STS41A-AWLB-R3 | mouser | 403-STS41A-AWLB-R3
6 | 6 |  |  | HW-C2-HW-STTH112A-A | STTH112A |  | STTH112A | mouser | 511-STTH112A
6 | 6 |  |  | HW-C2-HW-SXH-001T-P0-6-A | SXH-001T-P0.6 |  | SXH-001T-P0.6 | mouser | 306-SXH-001T-P0.6
4 | 4 |  |  | HW-C2-HW-SZMMSZ4678T1G-A | SZMMSZ4678T1G |  | SZMMSZ4678T1G | mouser | 863-SZMMSZ4678T1G
21 | 21 |  |  | HW-C2-HW-TESTPOINT-TH-RED-A | Testpoint TH, RED | CBPN-L3UB8-TestPoint | TestPoint | mouser | 534-5000
1 | 1 |  |  | HW-C2-HW-TPS389006ADJRTER-A | TPS389006ADJRTER |  | TPS389006ADJRTER | mouser | 595-TPS389006ADJRTER
2 | 2 |  |  | HW-C2-HW-TS40-66-50-R-260-SMT-TR-A | TS40-66-50-R-260-SMT-TR |  | TS40-66-50-R-260-SMT-TR | mouser | 179-TS406650R260S
2 | 2 |  |  | HW-C2-HW-TSW-103-18-G-D-A | TSW-103-18-G-D |  | TSW-103-18-G-D | mouser | 200-TSW10318GD
2 | 2 |  |  | HW-C2-HW-TSW-108-18-F-D-A | TSW-108-18-F-D |  | TSW-108-18-F-D | mouser | 200-TSW10818FD
1 | 1 |  |  | HW-C2-HW-TSW-110-18-T-D-A | TSW-110-18-T-D |  | TSW-110-18-T-D | mouser | 200-TSW11018TD
13 | 13 |  |  | HW-C2-HW-UCM1H101MCL1GS-A | UCM1H101MCL1GS |  | UCM1H101MCL1GS | mouser | 647-UCM1H101MCL1GS
60 | 60 |  |  | HW-C2-HW-UCS2D331MHD-A | UCS2D331MHD |  | UCS2D331MHD | mouser | 647-UCS2D331MHD
1 | 1 |  |  | HW-C2-HW-UJ2-B-HR-G-V-A | UJ2-B-HR-G-V |  | UJ2-B-HR-G-V | mouser | 179-UJ2-B-HR-G-V
18 | 18 |  |  | HW-C2-HW-VY1222M47Y5UQ6TV0-A | VY1222M47Y5UQ6TV0 |  | VY1222M47Y5UQ6TV0 | mouser | 72-VY1222M47Y5UQ6TV0
1 | 1 |  |  | HW-C2-PCB-CTRL-A | ControlBoard |  | ControlBoard | pcb | ControlBoard
1 | 1 |  |  | HW-C2-PCB-DCBUSCAP-A | DCBusCapacitorBoard |  | DCBusCapacitorBoard | pcb | DCBusCapacitorBoard
1 | 1 |  |  | HW-C2-PCB-DCFLT-A | DCBusFilter |  | DCBusFilter | pcb | DCBusFilter
1 | 1 |  |  | HW-C2-PCB-GD-A | GateDriver |  | GateDriver | pcb | GateDriver
1 | 1 |  |  | HW-C2-PCB-IO-A | IOBoard |  | IOBoard | pcb | IOBoard
1 | 1 |  |  | HW-C2-PLT-BSP-A | HW-C2-BSP-A |  | HW-C2-BSP-A | sendcutsend | HW-C2-BSP-A
1 | 1 |  |  | HW-C2-PLT-CHSP-A | HW-C2-CHSP-A |  | HW-C2-CHSP-A | sendcutsend | HW-C2-CHSP-A
27 | 27 |  |  | HW-C2-RES-10K-A | 10k 1210 | CBPN-B3D5Z-10k | 10k | mouser | 603-AC1210JR-0710KL
4 | 4 |  |  | HW-C2-RES-120-A | 120 1210 | CBPN-K6UIE-120 | 120 | mouser | 603-AC1210FR-07120RL
17 | 17 |  |  | HW-C2-RES-1K-A | 1k 1210 | CBPN-F0NOB-1k | 1k | mouser | 603-RC1210FR-071KL
12 | 12 |  |  | HW-C2-RES-2R7-A | 2.7 ohm 1210 | CBPN-VEDNZ-27 | 2.7 | mouser | 667-ERJ-14BQF2R7U
16 | 16 |  |  | HW-C2-RES-20K-A | 20k 1210 resistor | CBPN-ZYB6M-20k | 20k | mouser | 667-ERJ-P14F2002U
1 | 1 |  |  | HW-C2-RES-220-A | 220 1210 | CBPN-SZ7LV-220 | 220 | mouser | 603-RC1210FR-07220RL
3 | 3 |  |  | HW-C2-RES-3K-A | 3k 1210 1% |  | 3k | mouser | 603-RC1210FR-073KL
3 | 3 |  |  | HW-C2-RES-4K7-A | 4.7k 1210 | CBPN-5Z102-47k | 4.7k | mouser | 71-CRCW12104K70FKEAH
1 | 1 |  |  | HW-C2-RES-499K-A | 499kohm 1210 resistor | CBPN-IPSO6-499k | 499k | mouser | 667-ERJ-P14F4993U
2 | 2 |  |  | HW-C2-RES-560-A | 560ohm 1210 resistor | CBPN-HMOLG-560 | 560 | mouser | 667-ERJ-P14F5600U
16 | 16 |  |  | HW-C2-RES-250K-A | Thick Film Resistors - SMD 1/2watt 249Kohms 1% | CBPN-MZWIW-250k | 250k | mouser | 71-CRCW1210-249K-E3
1 | 1 |  |  | HW-C2-WH-TSBCM-A | CapacitorTempSenseHarness |  | CapacitorTempSenseHarness | assembly
4 | 4 |  |  | HW-C2-WH-CS-A | CurrentSenseHarness |  | CurrentSenseHarness | assembly
1 | 1 |  |  | HW-C2-WH-GDVS-A | GDVSHarness |  | GDVSHarness | assembly
2 | 2 |  |  | HW-C2-WH-TSIGBT-A | TempSenseHarness |  | TempSenseHarness | assembly

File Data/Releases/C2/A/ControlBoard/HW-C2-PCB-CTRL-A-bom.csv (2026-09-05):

Designator | Designation | Footprint | Quantity | DNP | Exclude from BOM
C2,C3,C4,C5,C21,C22,C23,C24,C25,C29,C38,C39,C42,C43,C44,C45,C46,C47,C49,C50,C51 | 10nF | Capacitor_SMD:C_1210_3225Metric_Pad1.33x2.70mm_HandSolder | 21
C9,C10,C13,C14,C15,C17,C27,C28,C31,C32,C34,C41,C135,C137,C138,C139,C142,C143,C144,C145,C146,C149,C182,C183,C184,C185,C186,C187,C188,C193,C194,C195,C197,C201,C202,C203 | 100nF | Capacitor_SMD:C_1210_3225Metric_Pad1.33x2.70mm_HandSolder | 36
C11,C12,C40,C134,C136,C147,C192,C200 | 1uF | Capacitor_SMD:C_1210_3225Metric_Pad1.33x2.70mm_HandSolder | 8
C18,C19,C20,C35,C36,C37 | 22pF | Capacitor_SMD:C_1210_3225Metric_Pad1.33x2.70mm_HandSolder | 6 | DNP
C26,C30,C33,C48 | 22pF | Capacitor_SMD:C_1210_3225Metric_Pad1.33x2.70mm_HandSolder | 4
C140,C141,C189,C198,C208,C209,C210 | 10uF | Capacitor_SMD:C_1210_3225Metric_Pad1.33x2.70mm_HandSolder | 7
C190,C191 | 2.2uF | Capacitor_SMD:C_1210_3225Metric_Pad1.33x2.70mm_HandSolder | 2
C204,C205,C206,C207 | 100nF | Capacitor_SMD:C_1210_3225Metric_Pad1.33x2.70mm_HandSolder | 4 | DNP
C211 | 10uF | Capacitor_SMD:C_1210_3225Metric_Pad1.33x2.70mm_HandSolder | 1 | DNP
FL1,FL2 | ACT45B-101-2P-TL003 | InverterCom:ACT45B1012PTL003 | 2
H1,H2,H3,H4,H5,H6,H7,H8 | 971350581 | InverterCom:971350581 | 8
IC1 | TPS389006ADJRTER | InverterCom:QFN50P300X300X80-17N-D | 1
IC2 | MAX22530AWE+ | InverterCom:SOIC127P1032X265-16N | 1
IC3,IC5,IC6,IC7 | ISO1042BDWVR | InverterCom:SOIC127P1150X280-8N | 4
IC4 | CY15B102Q-SXET | InverterCom:SOIC127P800X203-8N | 1
J1,J4,J5 | B2B-XH-AM_LF__SN_ | InverterCom:B2BXHAMLFSN | 3
J2 | TSW-110-21-L-D-LL | InverterCom:PinHeader_2x10_P2.54mm_Vertical-31mm | 1
J3,J6,J8,J9 | 22-04-1041 | InverterCom:SHDR4W64P0X250_1X4_950X580X1210P | 4
J7,J12 | SSW-108-01-L-D | InverterCom:SSW-108-01-L-D | 2
J10,J13 | SSW-103-01-L-D | InverterCom:SSW-103-01-L-D | 2
J14 | SSW-110-01-F-D | InverterCom:SSW-110-01-F-D | 1
J15 | 524265-E | InverterCom:524265E | 1
LED1 | LTST-C230CKT | InverterCom:LEDC3216X120N | 1
LED2 | LTST-C230GKT | InverterCom:LEDC3216X120N | 1
PS1,PS2,PS4 | RKE-1205S_H | InverterCom:RKE1205SH | 3
PS6 | RD7-12S033R | InverterCom:RD712S033R | 1
R1,R7,R17,R23 | 2k | Resistor_SMD:R_1210_3225Metric_Pad1.30x2.65mm_HandSolder | 4 | DNP
R2,R8,R18,R24,R30,R87,R91,R93,R95 | 1k | Resistor_SMD:R_1210_3225Metric_Pad1.30x2.65mm_HandSolder | 9
R3,R4,R5,R6,R9,R10,R11,R16,R19,R20,R21,R22,R25,R26,R27,R28 | 250k | Resistor_SMD:R_1210_3225Metric_Pad1.30x2.65mm_HandSolder | 16
R12,R31 | 4.7k | Resistor_SMD:R_1210_3225Metric_Pad1.30x2.65mm_HandSolder | 2
R14,R15,R39,R41,R43,R45,R47,R49,R51,R53,R55,R57,R59,R61,R63,R65,R67,R70,R71,R73,R88,R89,R90,R92,R94,R98,R99 | 10k | Resistor_SMD:R_1210_3225Metric_Pad1.30x2.65mm_HandSolder | 27
R29 | 3k | Resistor_SMD:R_1210_3225Metric_Pad1.30x2.65mm_HandSolder | 1
R37,R38 | 120 | Resistor_SMD:R_1210_3225Metric_Pad1.30x2.65mm_HandSolder | 2
R40,R42,R44,R46,R48,R50,R52,R54,R56,R58,R60,R62,R64,R66,R72,R100 | 20k | Resistor_SMD:R_1210_3225Metric_Pad1.30x2.65mm_HandSolder | 16
R68,R69 | 560 | Resistor_SMD:R_1210_3225Metric_Pad1.30x2.65mm_HandSolder | 2
R74,R75,R78,R79,R82,R83,R96 | 10k | Resistor_SMD:R_1210_3225Metric_Pad1.30x2.65mm_HandSolder | 7 | DNP
R76,R77,R80,R81,R84,R85 | 560 | Resistor_SMD:R_1210_3225Metric_Pad1.30x2.65mm_HandSolder | 6 | DNP
R86 | 499k | Resistor_SMD:R_1210_3225Metric_Pad1.30x2.65mm_HandSolder | 1
R97 | 1k | Resistor_SMD:R_1210_3225Metric_Pad1.30x2.65mm_HandSolder | 1 | DNP
S1,S2 | TS40-66-50-R-260-SMT-TR | InverterCom:TS406650R260SMTTR | 2
TP1,TP3,TP4,TP5,TP6 | TestPoint | TestPoint:TestPoint_Loop_D2.54mm_Drill1.5mm_Beaded | 5
U1 | STM32H723ZGT6 | Package_QFP:LQFP-144_20x20mm_P0.5mm | 1
U2,U5,U6 | ISO1212DBQ | Package_SO:SSOP-16_3.9x4.9mm_P0.635mm | 3 | DNP
U3 | LT3080IQ#PBF | Package_TO_SOT_SMD:TO-263-5_TabPin6 | 1
U4 | ISO1212DBQ | Package_SO:SSOP-16_3.9x4.9mm_P0.635mm | 1
U7,U8 | BTS462TATMA1 | Package_TO_SOT_SMD:TO-252-4 | 2
U9 | STM32G474RCT3 | Package_QFP:LQFP-64_10x10mm_P0.5mm | 1
U10,U11,U12,U13 | LM397 | Package_TO_SOT_SMD:SOT-23-5 | 4 | DNP
U14 | STS41A-AWLB-R3 | InverterCom:STS41AAWLBR3 | 1
Y1,Y2 | 8MHz | Crystal:Crystal_HC49-4H_Vertical | 2
Z1,Z2,Z3,Z4 | SZMMSZ4678T1G | InverterCom:SOD3716X135N | 4
Z5,Z6,Z7 | MM3Z3V0ST1G | InverterCom:SOD2512X100N | 3
Z8 | MM3Z3V0ST1G | InverterCom:SOD2512X100N | 1 | DNP

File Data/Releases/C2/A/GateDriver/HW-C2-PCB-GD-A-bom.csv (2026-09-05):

Designator | Designation | Footprint | Quantity | DNP | Exclude from BOM
C1,C74,C75,C77,C78,C80,C81,C82 | UCM1H101MCL1GS | InverterCom:CAPAE660X800N | 8
C2,C5,C6,C9,C14,C17,C18,C21,C26,C29,C30,C33,C38,C41,C42,C45,C50,C53,C54,C57,C62,C65,C66,C69,C76,C79,C83,C85,C87,C89,C91,C93 | 100nF | Capacitor_SMD:C_1210_3225Metric_Pad1.33x2.70mm_HandSolder | 32
C3,C4,C7,C10,C15,C16,C19,C22,C27,C28,C31,C34,C39,C40,C43,C46,C51,C52,C55,C58,C63,C64,C67,C70,C84,C86,C88,C90,C92,C94 | 10uF | Capacitor_SMD:C_1210_3225Metric_Pad1.33x2.70mm_HandSolder | 30
C8,C11,C12,C20,C23,C24,C32,C35,C36,C44,C47,C48,C56,C59,C60,C68,C71,C72 | 10uF | Capacitor_SMD:C_1210_3225Metric_Pad1.33x2.70mm_HandSolder | 18 | DNP
C13,C25,C37,C49,C61,C73 | 220pF | Capacitor_SMD:C_1210_3225Metric_Pad1.33x2.70mm_HandSolder | 6
D1,D2,D4,D5,D7,D8,D10,D11,D13,D14,D16,D17 | BAT54WS-7-F | InverterCom:SOD2513X120N | 12
D3,D6,D9,D12,D15,D18 | STTH112A | InverterCom:DIOM5126X265N | 6
H1,H2,H3,H4,H5,H6,H7,H8 | 971150581 | InverterCom:971150581 | 8
IC1,IC2,IC3,IC4,IC5,IC6 | NCV57100DWR2G | InverterCom:SOIC127P1030X265-16N | 6
J1,J2,J3 | 524265-E | InverterCom:524265E | 3
J6 | SSW-110-01-F-D | Connector_PinSocket_2.54mm:PinSocket_2x10_P2.54mm_Vertical | 1
LED1 | LTST-C230GKT | InverterCom:LEDC3216X120N | 1
LED2 | LTST-C230CKT | InverterCom:LEDC3216X120N | 1
PS1,PS2,PS3,PS4,PS5,PS6 | MGJ2D121509MPC-R7 | InverterCom:MGJ2D121509MPCR7 | 6
R1 | 4.7k | Resistor_SMD:R_1210_3225Metric_Pad1.30x2.65mm_HandSolder | 1
R2 | 220 | Resistor_SMD:R_1210_3225Metric_Pad1.30x2.65mm_HandSolder | 1
R3,R4,R7,R8,R11,R12,R15,R16,R19,R20,R23,R24 | 2.7 | Resistor_SMD:R_1210_3225Metric_Pad1.30x2.65mm_HandSolder | 12
R5,R9,R13,R17,R21,R25 | 1k | Resistor_SMD:R_1210_3225Metric_Pad1.30x2.65mm_HandSolder | 6 | DNP
R6,R10,R14,R18,R22,R26,R27,R30 | 1k | Resistor_SMD:R_1210_3225Metric_Pad1.30x2.65mm_HandSolder | 8
R28,R29 | 3k | Resistor_SMD:R_1210_3225Metric_Pad1.30x2.65mm_HandSolder | 2
R31,R32 | 120 | Resistor_SMD:R_1210_3225Metric_Pad1.30x2.65mm_HandSolder | 2
TP1,TP2,TP3,TP4,TP5,TP6,TP7,TP8,TP9,TP10,TP11,TP12,TP13,TP14,TP15,TP16 | TestPoint | TestPoint:TestPoint_Loop_D2.54mm_Drill1.5mm_Beaded | 16
U5,U6 | BTS462TATMA1 | Package_TO_SOT_SMD:TO-252-4 | 2
Z1,Z2 | MM3Z3V0ST1G | InverterCom:SOD2512X100N | 2

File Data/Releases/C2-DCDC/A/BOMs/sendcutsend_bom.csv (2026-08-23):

Quantity | Internal P/N | Description | Customer Part No. | Manufacturer Part No. | Vendor | Vendor P/N
6 | HW-C2-3DP-DC-LINK-MODULE-HOLDER-SP-A | DC Link Module Holder Spacer - Printed |  | DC Link Module Holder Spacer - Printed | sendcutsend | DC Link Module Holder Spacer - Printed
3 | HW-C2-3DP-DCLSPCR-PRINTED-A | HW-C2-DCLSPCR-PRINTED-B |  | HW-C2-DCLSPCR-PRINTED-B | sendcutsend | HW-C2-DCLSPCR-PRINTED-B
1 | HW-C2-3DP-SHELL-PRINTED-A | HW-C2-SHELL-PRINTED-A |  | HW-C2-SHELL-PRINTED-A | sendcutsend | HW-C2-SHELL-PRINTED-A
2 | HW-C2-BB-DCLBB-A | HW-C2-DCLBB-A |  | HW-C2-DCLBB-A | sendcutsend | HW-C2-DCLBB-A
3 | HW-C2-BB-PBB-A | HW-C2-PBB-A |  | HW-C2-PBB-A | sendcutsend | HW-C2-PBB-A
1 | HW-C2-HW-DC-LINK-MODULE-HOLDER-A | DC Link Module Holder - 200V Class |  | DC Link Module Holder - 200V Class | sendcutsend | DC Link Module Holder - 200V Class
1 | HW-C2-HW-THERMAL-PAD-CUTTING-STEN-A | Thermal Pad Cutting Stencil |  | Thermal Pad Cutting Stencil | sendcutsend | Thermal Pad Cutting Stencil
1 | HW-C2-PLT-BSP-A | HW-C2-BSP-A |  | HW-C2-BSP-A | sendcutsend | HW-C2-BSP-A
1 | HW-C2-PLT-CHSP-A | HW-C2-CHSP-B |  | HW-C2-CHSP-B | sendcutsend | HW-C2-CHSP-B

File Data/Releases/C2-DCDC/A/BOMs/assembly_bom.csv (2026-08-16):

Quantity | Internal P/N | Description | Customer Part No. | Manufacturer Part No. | Vendor | Vendor P/N
1 | HW-C2-WH-TSBCM-A | CapacitorTempSenseHarness |  | CapacitorTempSenseHarness | assembly
4 | HW-C2-WH-CS-A | CurrentSenseHarness |  | CurrentSenseHarness | assembly
1 | HW-C2-WH-GDVS-A | GDVSHarness |  | GDVSHarness | assembly
2 | HW-C2-WH-TSIGBT-A | TempSenseHarness |  | TempSenseHarness | assembly

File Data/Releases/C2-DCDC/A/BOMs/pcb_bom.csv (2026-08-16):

Quantity | Internal P/N | Description | Customer Part No. | Manufacturer Part No. | Vendor | Vendor P/N
1 | HW-C2-PCB-CTRL-A | ControlBoard |  | ControlBoard | pcb | ControlBoard
1 | HW-C2-PCB-DCBUSCAP-A | DCBusCapacitorBoard |  | DCBusCapacitorBoard | pcb | DCBusCapacitorBoard
1 | HW-C2-PCB-DCFLT-A | DCBusFilter |  | DCBusFilter | pcb | DCBusFilter
1 | HW-C2-PCB-GD-A | GateDriver |  | GateDriver | pcb | GateDriver
1 | HW-C2-PCB-IO-A | IOBoard |  | IOBoard | pcb | IOBoard

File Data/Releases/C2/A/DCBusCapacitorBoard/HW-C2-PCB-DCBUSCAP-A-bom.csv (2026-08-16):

Designator | Designation | Footprint | Quantity | DNP | Exclude from BOM
C1,C2,C3,C4,C5,C6,C7,C8,C9,C10,C11,C12,C13,C14,C15,C16,C17,C18,C19,C20,C21,C22,C23,C24,C25,C26,C27,C28,C29,C30,C31,C32,C33,C34,C35,C36,C37,C38,C39,C40,C41,C42,C43,C44,C45,C46,C47,C48,C49,C50,C51,C52,C53,C54,C55,C56,C57,C58,C59,C60 | UCS2D331MHD | CAPPRD750W80D1800H3700 | 60
H13,H14,H15,H16,H17,H18,H19,H20 | 9774030592R | 9774030592R | 8

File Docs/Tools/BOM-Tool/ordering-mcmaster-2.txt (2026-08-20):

A paste box appears; it accepts most formats (part number + quantity per line).

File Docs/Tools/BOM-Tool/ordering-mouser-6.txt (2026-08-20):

On the Mapping step, assign the column categories so Mouser knows which is which: Mouser Part Number and Quantity (usually auto-detected, since the CSV is already in Mouser's column order). Then click Next.

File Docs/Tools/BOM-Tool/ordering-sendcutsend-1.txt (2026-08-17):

Go to sendcutsend.com and click GET STARTED (make an account if it's your first time).

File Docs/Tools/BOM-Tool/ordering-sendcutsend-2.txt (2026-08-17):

On the Parts page, drop in or upload the part's STEP file (Download STEP above). One part at a time.

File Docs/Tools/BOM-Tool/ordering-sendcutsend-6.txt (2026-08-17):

Add the services listed on the part's spec card (Bending, Tapping, Countersinking, ...).

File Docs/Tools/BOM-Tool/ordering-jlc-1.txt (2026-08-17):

Go to jlcpcb.com and click Order Now (or use the instant quote form).

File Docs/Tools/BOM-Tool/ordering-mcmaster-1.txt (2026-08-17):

On mcmaster.com, open the Order page and click Paste part numbers and quantities.

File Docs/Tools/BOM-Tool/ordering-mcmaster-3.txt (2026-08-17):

Click Copy McMaster order paste to clipboard above, paste it into the box, and click ADD.

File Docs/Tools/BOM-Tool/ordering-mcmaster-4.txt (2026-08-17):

Review the order lines (quantities, pack sizes, prices), then check out.

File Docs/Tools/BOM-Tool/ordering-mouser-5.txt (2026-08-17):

Browse to the Mouser CSV you downloaded from this page and click Upload a file.

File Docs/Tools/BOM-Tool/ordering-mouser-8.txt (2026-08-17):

Review every matched line: check availability and design risk, and make substitutions where a part is out of stock or deprecated. Then select all lines and click Buy selected items to add them to your cart.

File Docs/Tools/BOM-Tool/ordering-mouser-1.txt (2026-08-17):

Create a Mouser account or log in (Account & Orders → Log In; new customers start here).

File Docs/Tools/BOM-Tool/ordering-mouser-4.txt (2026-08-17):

Choose Upload Spreadsheet and select the Mouser CSV you downloaded from this page.

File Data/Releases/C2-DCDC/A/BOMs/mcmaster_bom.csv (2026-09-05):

Quantity | Internal P/N | Description | Customer Part No. | Manufacturer Part No. | Vendor | Vendor P/N
2 | HW-C2-MECH-1568A52-A | 1568A52 |  | 1568A52 | mcmaster | 1568A52
1 | HW-C2-MECH-1821A55-A | 1821A55 |  | 1821A55 | mcmaster | 1821A55
1 | HW-C2-MECH-5891T56-A | 5891T56 |  | 5891T56 | mcmaster | 5891T56
8 | HW-C2-MECH-6926K352-A | 6926K352 |  | 6926K352 | mcmaster | 6926K352
5 | HW-C2-MECH-6926K56-A | 6926K56 |  | 6926K56 | mcmaster | 6926K56
1 | HW-C2-MECH-7381K23-A | 7381K23 |  | 7381K23 | mcmaster | 7381K23
1 | HW-C2-MECH-90128A232-A | 90128A232 |  | 90128A232 | mcmaster | 90128A232
6 | HW-C2-MECH-90166A718-A | 90166A718 |  | 90166A718 | mcmaster | 90166A718
1 | HW-C2-MECH-90225A102-A | 90225A102 |  | 90225A102 | mcmaster | 90225A102
14 | HW-C2-MECH-90720A550-A | 90720A550 |  | 90720A550 | mcmaster | 90720A550
4 | HW-C2-MECH-91292A108-A | 91292A108 |  | 91292A108 | mcmaster | 91292A108
1 | HW-C2-MECH-91292A117-A | 91292A117 |  | 91292A117 | mcmaster | 91292A117
1 | HW-C2-MECH-91292A134-A | 91292A134 |  | 91292A134 | mcmaster | 91292A134
1 | HW-C2-MECH-91458A112-A | 91458A112 |  | 91458A112 | mcmaster | 91458A112
1 | HW-C2-MECH-91477A141-A | 91477A141 |  | 91477A141 | mcmaster | 91477A141
1 | HW-C2-MECH-91502A180-A | 91502A180 |  | 91502A180 | mcmaster | 91502A180
1 | HW-C2-MECH-91502A183-A | 91502A183 |  | 91502A183 | mcmaster | 91502A183
4 | HW-C2-MECH-92125A228-A | 92125A228 |  | 92125A228 | mcmaster | 92125A228
4 | HW-C2-MECH-94180A351-A | 94180A351 |  | 94180A351 | mcmaster | 94180A351
6 | HW-C2-MECH-94669A190-A | 94669A190 |  | 94669A190 | mcmaster | 94669A190
6 | HW-C2-MECH-94669A196-A | 94669A196 |  | 94669A196 | mcmaster | 94669A196
12 | HW-C2-MECH-94669A199-A | 94669A199 |  | 94669A199 | mcmaster | 94669A199
12 | HW-C2-MECH-96738A257-A | 96738A257 |  | 96738A257 | mcmaster | 96738A257
1 | HW-C2-MECH-98044A224-A | 98044A224 |  | 98044A224 | mcmaster | 98044A224

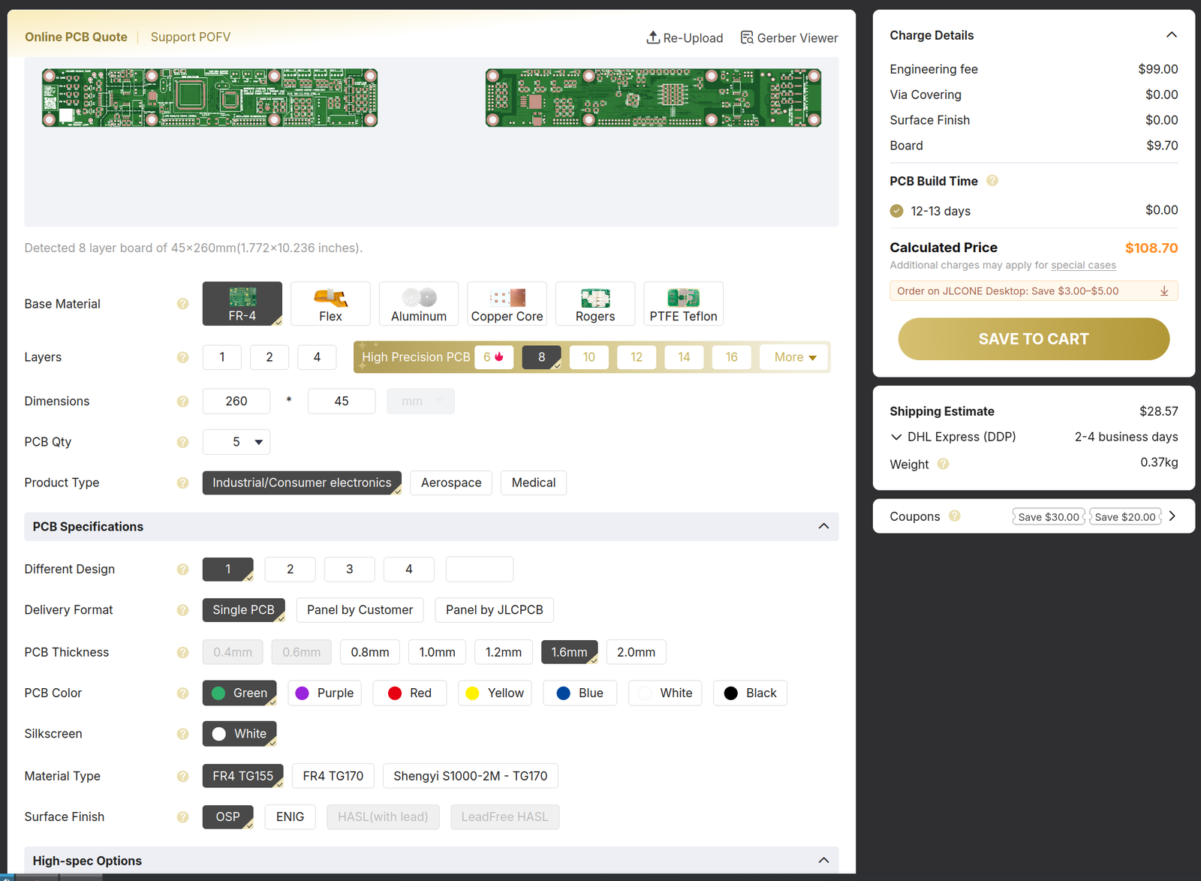
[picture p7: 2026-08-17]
Docs/Tools/BOM-Tool/ordering-jlc-3.png

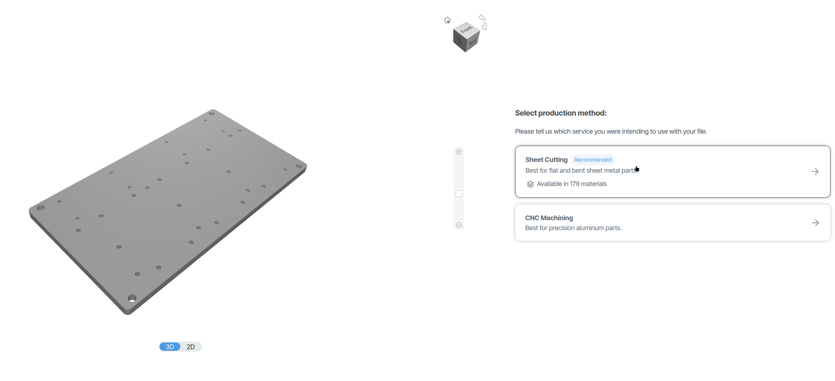
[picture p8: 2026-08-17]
Docs/Tools/BOM-Tool/ordering-sendcutsend-3.png

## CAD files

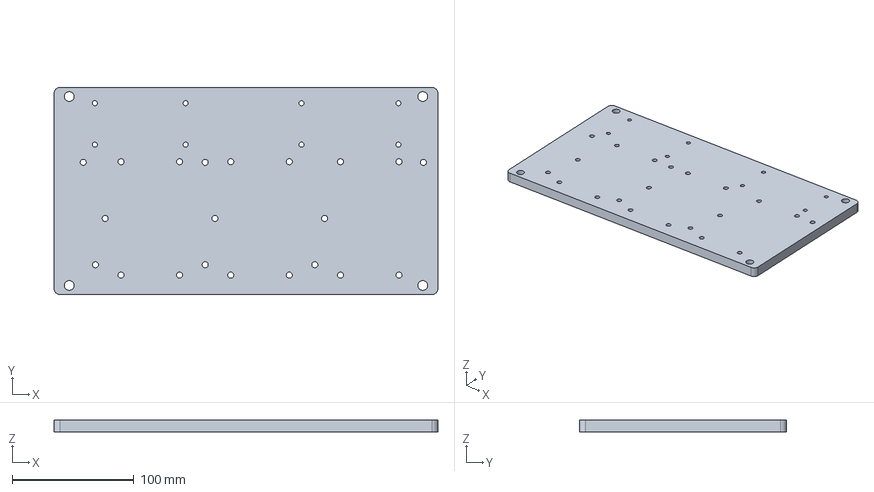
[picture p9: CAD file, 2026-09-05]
Data/Releases/C2-DCDC/A/Mech/HW-C2-BSP-A/HW-C2-BSP-A.step
315.0 x 170.0 x 10.0 mm

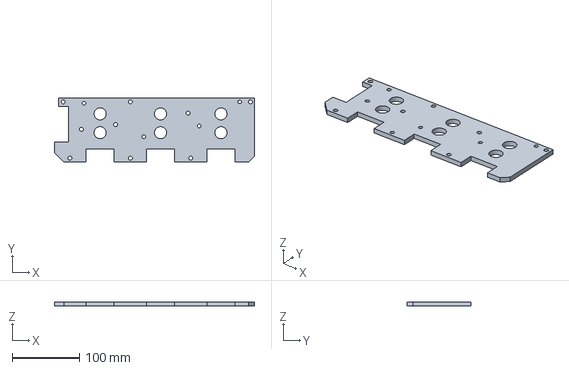
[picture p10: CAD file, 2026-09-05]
Data/Releases/C2-DCDC/A/Mech/HW-C2-CHSP-B/HW-C2-CHSP-B.step
298.0 x 96.0 x 6.35 mm

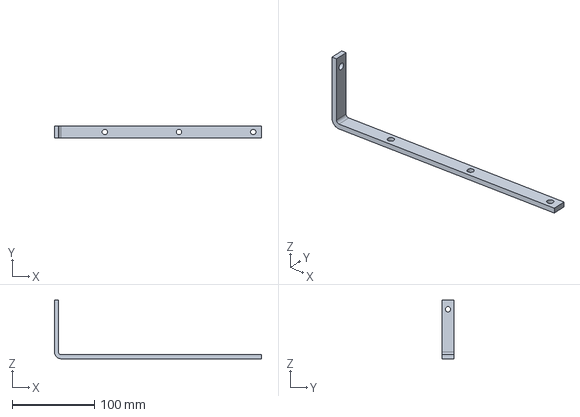
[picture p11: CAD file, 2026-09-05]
Data/Releases/C2-DCDC/A/Mech/HW-C2-DCLBB-A/HW-C2-DCLBB-A.step
251.0 x 14.0 x 71.0 mm

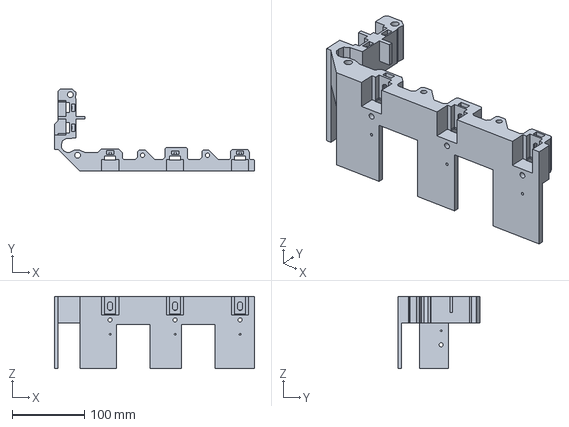
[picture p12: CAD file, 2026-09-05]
Data/Releases/C2-DCDC/A/Mech/HW-C2-DCLMH-200-PRINTED-B/HW-C2-DCLMH-200-PRINTED-B.step
277.0 x 114.0 x 100.0 mm

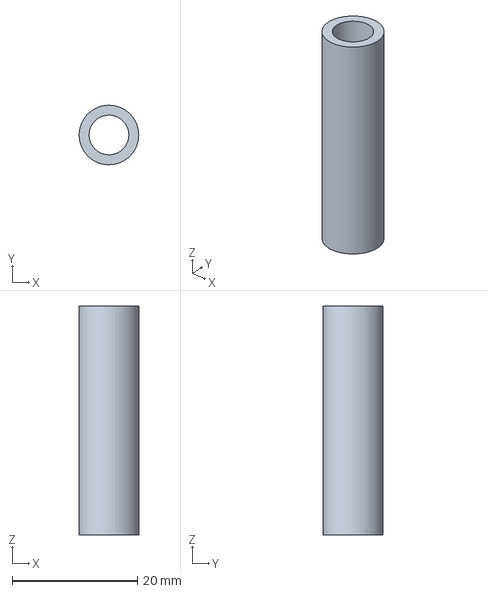
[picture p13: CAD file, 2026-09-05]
Data/Releases/C2-DCDC/A/Mech/HW-C2-DCLMH-200-SPCR-PRINTED-A/HW-C2-DCLMH-200-SPCR-PRINTED-A.step
9.49 x 9.50 x 36.5 mm

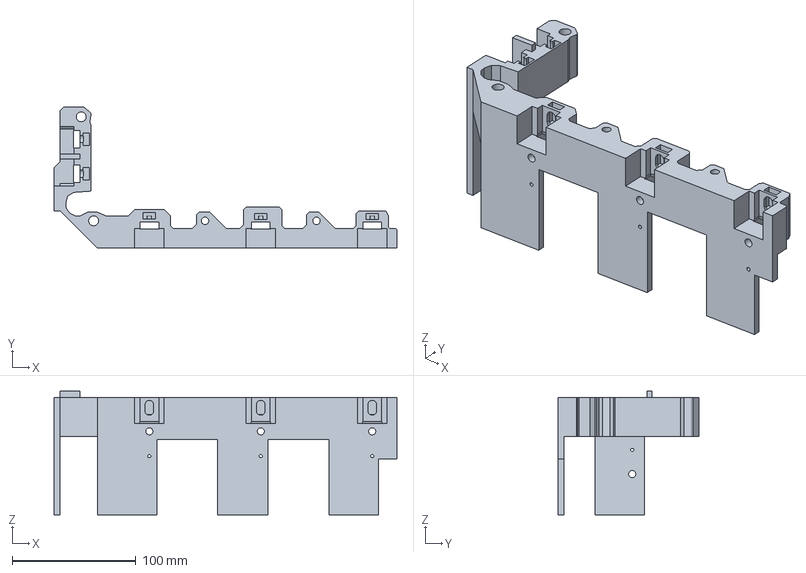
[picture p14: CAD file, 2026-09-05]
Data/Releases/C2-DCDC/A/Mech/HW-C2-DCLMH-450-PRINTED-A/HW-C2-DCLMH-450-PRINTED-A.step
277.0 x 114.0 x 100.0 mm

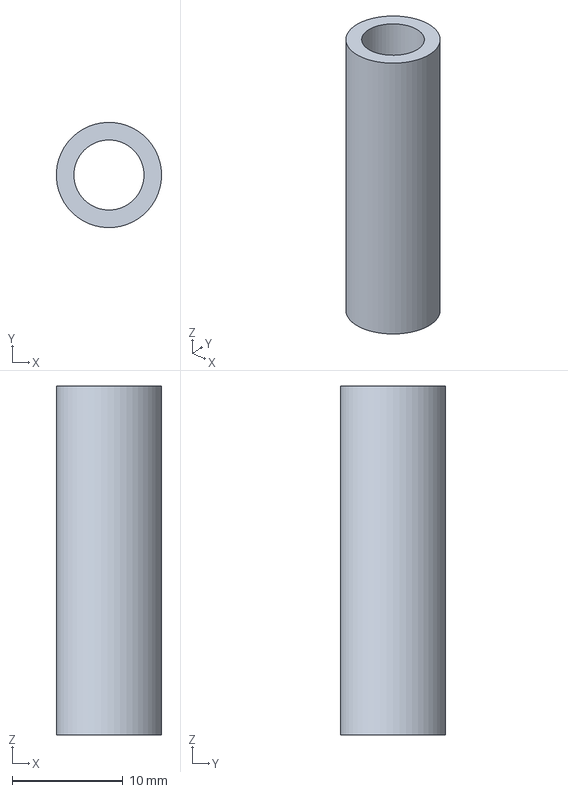
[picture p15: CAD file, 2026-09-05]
Data/Releases/C2-DCDC/A/Mech/HW-C2-DCLMH-450-SPCR-PRINTED-A/HW-C2-DCLMH-450-SPCR-PRINTED-A.step
9.49 x 9.50 x 31.5 mm

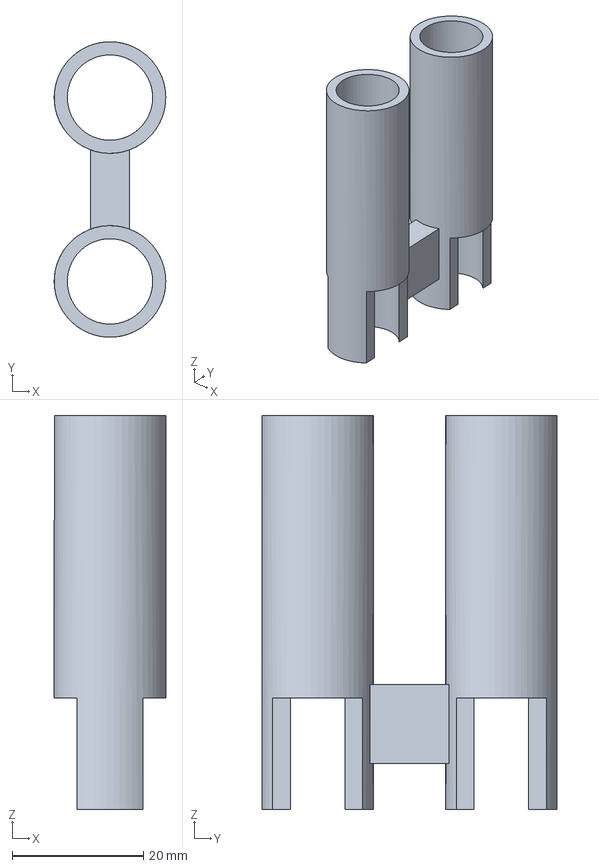
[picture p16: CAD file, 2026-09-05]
Data/Releases/C2-DCDC/A/Mech/HW-C2-DCLSPCR-PRINTED-B/HW-C2-DCLSPCR-PRINTED-B.step
17.0 x 45.0 x 60.0 mm

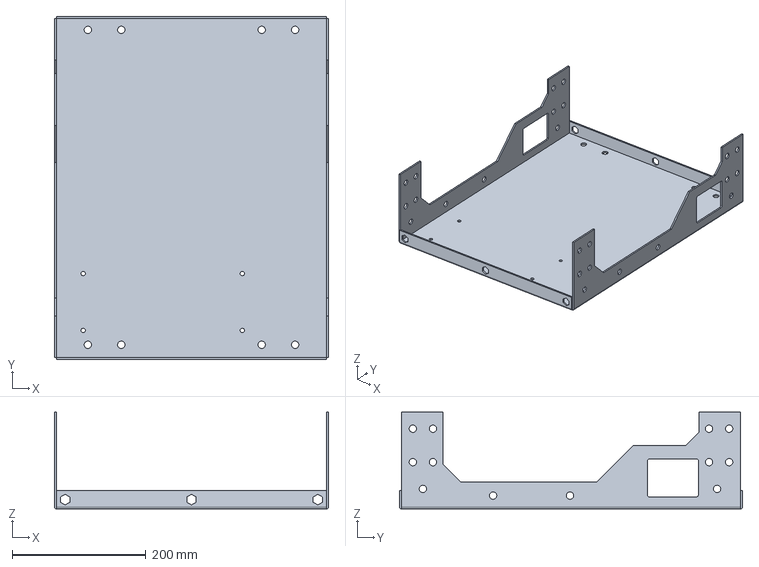
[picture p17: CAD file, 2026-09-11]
Data/Releases/C2-DCDC/A/Mech/HW-C2-FR-BSP-A/HW-C2-FR-BSP-A.step
410.0 x 513.0 x 145.0 mm

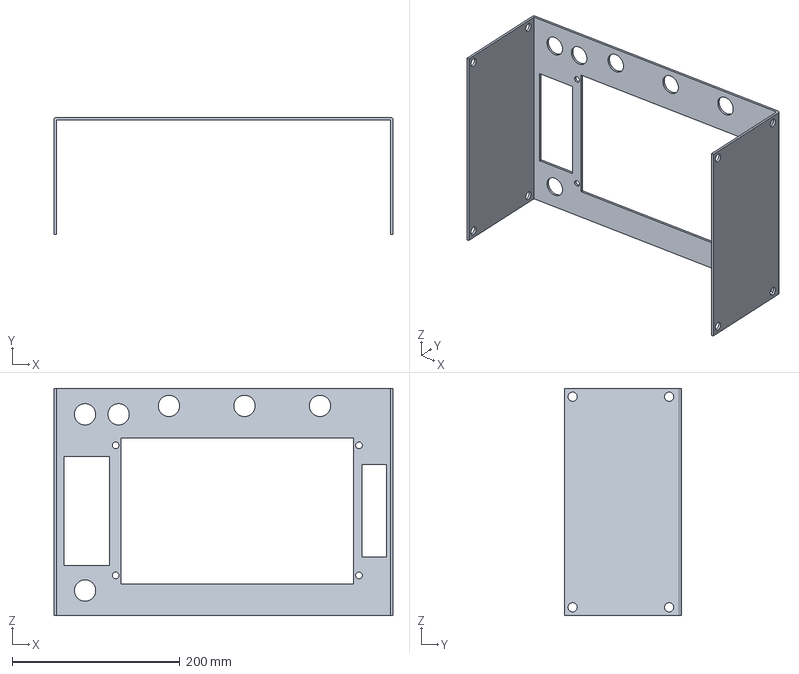
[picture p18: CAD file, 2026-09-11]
Data/Releases/C2-DCDC/A/Mech/HW-C2-FR-CLPHLD-A/HW-C2-FR-CLPHLD-A.step
404.0 x 140.0 x 271.0 mm

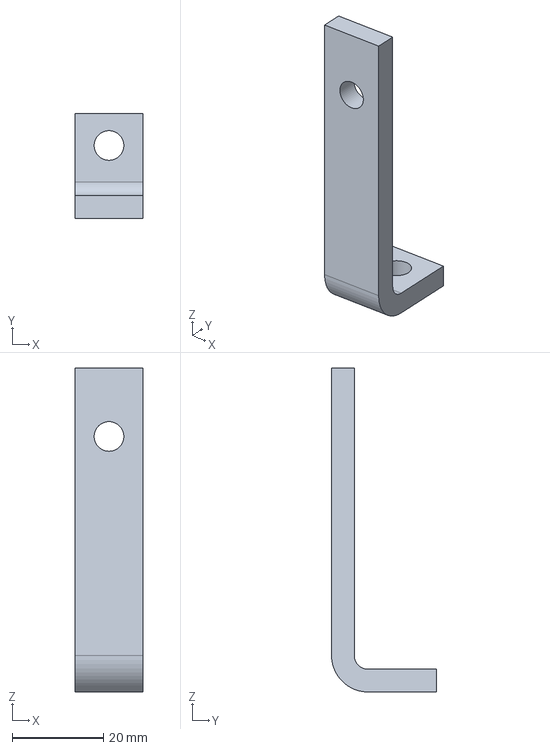
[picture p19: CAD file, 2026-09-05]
Data/Releases/C2-DCDC/A/Mech/HW-C2-PBB-A/HW-C2-PBB-A.step
15.0 x 23.0 x 71.0 mm

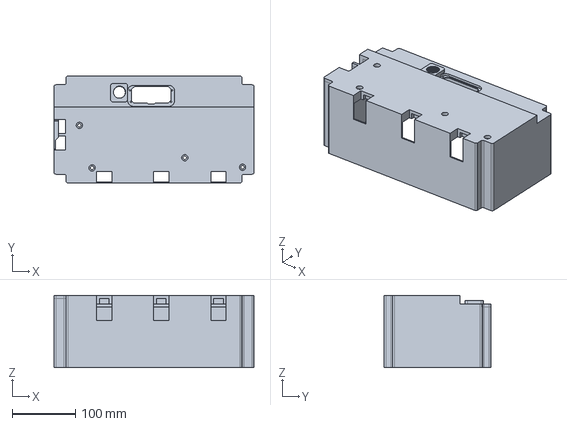
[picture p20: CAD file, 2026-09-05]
Data/Releases/C2-DCDC/A/Mech/HW-C2-SHELL-PRINTED-A/HW-C2-SHELL-PRINTED-A.step
315.0 x 169.0 x 114.0 mm

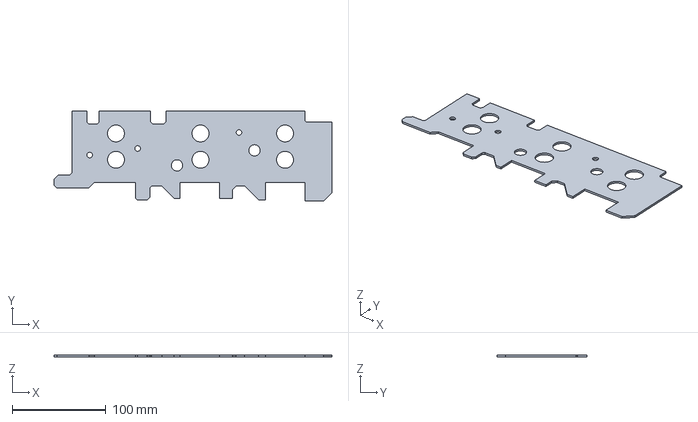
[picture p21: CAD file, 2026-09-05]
Data/Releases/C2-DCDC/A/Mech/HW-C2-THRMLPD-STNCL-A/HW-C2-THRMLPD-STNCL-A.step
296.0 x 96.0 x 2.00 mm

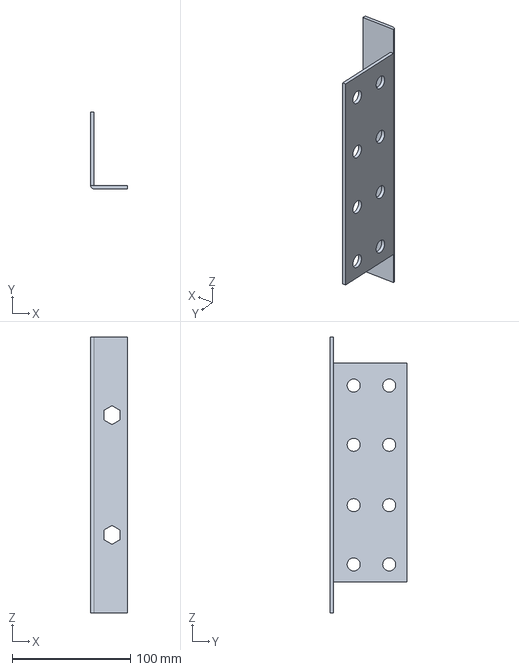
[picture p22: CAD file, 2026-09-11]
Data/Releases/C2-DCDC/A/Mech/HW-C3-FR-CSP-A/HW-C3-FR-CSP-A.step
31.0 x 65.0 x 233.0 mm

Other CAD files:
Data/Releases/C2-DCDC/A/Mech/HW-C3-FR-FRNLID-A/HW-C3-FR-FRNLID-A.step
Data/Releases/C2/A/ControlBoard/HW-C2-PCB-CTRL-A.step
Data/Releases/C2/A/DCBusCapacitorBoard/HW-C2-PCB-DCBUSCAP-A.step
Data/Releases/C2/A/DCBusFilter/HW-C2-PCB-DCFLT-A.step
Data/Releases/C2-DCDC/A/Mech/HW-C2-BSP-A/HW-C2-BSP-A.stl
Data/Releases/C2-DCDC/A/Mech/HW-C2-CHSP-B/HW-C2-CHSP-B.stl
Data/Releases/C2-DCDC/A/Mech/HW-C2-DCLBB-A/HW-C2-DCLBB-A.stl
Data/Releases/C2-DCDC/A/Mech/HW-C2-DCLMH-200-PRINTED-B/HW-C2-DCLMH-200-PRINTED-B.stl
Data/Releases/C2-DCDC/A/Mech/HW-C2-DCLMH-200-SPCR-PRINTED-A/HW-C2-DCLMH-200-SPCR-PRINTED-A.stl
Data/Releases/C2-DCDC/A/Mech/HW-C2-DCLMH-450-PRINTED-A/HW-C2-DCLMH-450-PRINTED-A.stl
Data/Releases/C2-DCDC/A/Mech/HW-C2-DCLMH-450-SPCR-PRINTED-A/HW-C2-DCLMH-450-SPCR-PRINTED-A.stl
Data/Releases/C2-DCDC/A/Mech/HW-C2-DCLSPCR-PRINTED-B/HW-C2-DCLSPCR-PRINTED-B.stl
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

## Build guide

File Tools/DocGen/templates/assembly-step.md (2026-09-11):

---
# Template for an ordered assembly-guide step.
# Place under Docs/Hardware/Power-Stages/C2/Assembly-Guide/<N>_<Chapter>/<N>_<Step>/
doctype: Assembly Guide
doc_id: OV-C2-AG-NN-NN
title: N.N Step Title
product_line: openvvvf
applies_to:
  - chassis-size-2
version: "0.1"
date: "YYYY-MM-DD"
status: draft
description: One-sentence summary of this assembly step.
nav_order: 3NN
normative_refs:
  - OV-C2-AG-INDEX
  - OV-C2-UM-INDEX
---

# N.N Step Title

Brief description of what this step accomplishes.

## Required materials and tools

| Item | Qty | Notes |
|---|-----|---|
| ...  | ... | ... |

## Procedure

1. ...
2. ...

## Inspection and verification

- ...

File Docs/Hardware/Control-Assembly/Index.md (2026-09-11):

---
doctype: Index
doc_id: OV-CA-INDEX
title: Control Assembly
product_line: openvvvf
applies_to:
  - openvvvf-control-module
version: "0.1"
date: "2026-08-07"
description: The reusable OpenVVVF control module - user hardware manual and software manual.
nav_order: 100
---

# Control Assembly

The control assembly is the reusable inverter brain of OpenVVVF. It is a dual-MCU traction-inverter / VCU control board that can be paired with any compatible power stage.

- **[User Hardware Manual](User-Hardware-Manual/Index.md)** - Board layout, connectors, pinout, mounting, thermal, electrical interface, HVIL, and safe-state behavior. *(Under development - placeholder.)*
- **[Software Manual](Software-Manual/Index.md)** - Base firmware image overview, flashing procedure, RTE host setup, and how to build and load custom code. *(Under development - placeholder.)*
- **[Assembly Guide](Assembly-Guide/Index.md)** - Step-by-step assembly procedures for the control module.

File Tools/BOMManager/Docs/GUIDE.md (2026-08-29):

# BOM Manager - Usage Guide

The fab-time tool for this project. It collects the BOM from your KiCad
boards, wiring harnesses, mechanical hardware, and fabricated parts; helps you
price and order everything (with pack-size math and your on-hand stock); and
builds the release package (order files + full PDF report).

## Setup

```bash
cd Hardware/BOMManager
pip install -r requirements.txt
pip install -r requirements-dev.txt   # pytest, for the test suite
python3 -m pytest tests/              # sanity check
```

`Config.yaml` (vendor API keys) is optional: everything works on manual
prices and pasted cart/order imports.

## The shell

```bash
python3 bom.py            # interactive
python3 bom.py status     # one-shot (any command works this way)
```

Everything below is a shell command. The shell remembers your chassis
(`chassis <name>` to switch) and never dies on a bad command; fix and retry.

## Daily loop: parts, prices, packs, stock

```text
status                    # dashboard: lines, priced coverage, attention items
parts                     # every BOM line with vendor PN + price status
parts --unpriced          # just what's missing prices
add                       # wizard: walk lines that need entries
price 94669A199 3.10      # set a price (per piece, or per pack if packed)
pack 94669A199 25         # sold in boxes of 25 -> ordering counts packs
stock 94669A199 19        # leftovers on your shelf (local, gitignored)
exclude <query>           # mark a part DNO (do not order)
forget <query>            # delete a part's database entry
```

Rules of thumb:

- **Qty = pieces the design needs**, never packs. `pack` carries the pack
  size; ordering does `ceil((need − stock) / pack_size)`.
- Prices are per **order unit** (per piece normally, per pack when packed).
- The query for price/pack/stock is a vendor PN, internal PN, or description
  text; a picker appears when it's ambiguous.

## MechanicalBOM.txt is owned by the tool

Don't hand-edit it. It holds purchased chassis hardware (any vendor string):

```text
mech                            # list with prices
mech add McMaster 94669A199 12 M3x10 SHCS
mech set 94669A199 6
mech rm 94669A199
```

Board-level parts and harness parts do **not** belong here; those come from
KiCad.

## Boards

Export each board's BOM **from the schematic editor** (Eeschema → Tools →
Generate BOM) as `Boards/<Board>/<Board>.csv` (beside the project). Both the
classic `Id;Designator;Footprint;Quantity;Designation` format and the KiCad
10 `Reference,Qty,Value,DNP,...` export work; DNP/excluded rows are skipped.
`Fab/` holds gerbers/drill; those get zipped for the fab house.

Parts covered elsewhere (e.g. a connector that ships with a harness) should
be **Exclude from BOM** in the schematic so they aren't double-ordered.

```text
fab pcb-price ControlBoard 25.24    # set a board's fab price
import jlcpcb                        # or paste a JLCPCB cart to set them all
```

## Wiring harnesses

One folder per harness under `Wiring/<Name>/`: a KiCad schematic (layout not
needed) plus the schematic BOM export as `<Name>.csv` in the same folder.

```text
new harness GDVSHarness     # scaffolds folder + README + descriptor
```

- Components (connectors, crimps, wire) consolidate into the BOM like any
  other part; the harness itself appears as a `HW-C2-WH-...` assembly line.
- **Descriptor** comes from `new harness`, from the folder name when it's
  IPN-shaped (`HW-C2-WH-GD-A` or `HW-C2-WH-GD`, adopted with no prompt), or
  from a one-time prompt otherwise.
- **Building several per chassis?** The schematic documents ONE harness; add
  `info.txt` with `Qty=4` next to the CSV. The assembly line and all
  components multiply.

Current harnesses as an example: GDVS ×1, TSIGBT ×2, CS ×4, TSBCM ×1.

## Fabricated parts (SendCutSend & friends)

```text
new fab DC Link Bus Bar     # Mechanical/Fab/HW-C2-DCLBB-A/ + info.txt + README
```

Drop the STEP in, fill `info.txt` (or paste a cart into `import sendcutsend`
and it fills material/thickness/price/qty for you). `fab` shows readiness
(STEP ✓, info.txt ✓, price ✓, image ✓) and the same checklist lands in the
report.

## Ordering

```text
release
```

runs the full generate and prints an upload checklist. It also writes
**spares variants** under `FabricationData/BOMs/Variants/`:

- `standard/`: cheap parts (crimps, housings, passives) +25% (min +2)
- `generous/`: cheap parts +50% (min +5), **and** +1 each on medium parts
  ($1–$30: STM32s, NCV57100 gate drivers, gate-drive supplies)

Very expensive parts (IGBTs) and in-house assemblies are never spared. Each
variant directory has the full vendor CSV set + McMaster paste + a priced
Consolidated BOM; the tier totals print for comparison.

| Vendor | File | Where |
|---|---|---|
| Mouser | `BOMs/mouser_bom.csv` | Mouser BOM tool |
| DigiKey | `BOMs/digikey_bom.csv` | DigiKey BOM tool |
| McMaster | `McMaster_Order_Paste.txt` | cart "paste part numbers" box (quantities are packs; stock-covered lines omitted) |
| SendCutSend | `Mechanical/Fab/*/` STEPs | specs in the report |
| PCB | `PCB_Fab_Zips/*.zip` | your PCB vendor |

## Build variants

Distinct from the spares tiers above: a **build variant** is a different
configuration of the same chassis (e.g. a 450 V build that swaps the DC-link
capacitor bank). The schematic stays the design truth; the swap happens at BOM
level via `variants.yaml` in the chassis directory (under a configured
hardware root):

```yaml
default: 200v            # variant whose outputs land at FabricationData/ root
variants:
  200v:
    description: "200 V class - stock 60x UCS2D331MHD 330uF/200V bank"
    rules: []            # committed tree as-is
  450v:
    description: "450 V class - capacitor swap to 60x UCS2W680MHD 68uF/450V"
    rules:
      - exclude: {designation: UCS2D331MHD}           # case-insensitive exact
      - exclude: {source: HW-C2-DCLMH-200-PRINTED-B}  # board / fab folder name
      - add: {designation: UCS2W680MHD, footprint: CAPPRD750W80D1800H3700,
              category: board, source: DCBusCapacitorBoard, quantity: 60,
              description: "Nichicon 68uF 450V electrolytic"}
      - add: {fab: HW-C2-DCLMH-250-450-PRINTED-A, quantity: 1}
      - setqty: {designation: 98044A224, quantity: 30}  # qty-only change
```

- `exclude` drops items matching a designation (case-insensitive exact) or a
  source (board name / `Mechanical/Fab/` folder name). `setqty` changes only a
  line's quantity. A rule that matches nothing is an error: typos never
  silently no-op.
- `add` injects a synthetic part; the `add: {fab: FOLDER-NAME, quantity: N}`
  form pulls a `Mechanical/Fab/` folder (specs from its `info.txt`). Such a
  folder is **variant-only**: it stays out of the base BOM and appears only in
  the variants that add it. Descriptions/prices for added parts come from the
  part database like any other line.

`generate` with no `--variant` flag builds **all declared variants at once**.
The `default` variant writes to the usual `FabricationData/` root (paths and
bytes unchanged vs. a chassis with no variants.yaml); other variants write the
same file set to `FabricationData/Builds/<variant>/` (PCB zips skipped: the
boards are identical). Use `--variant 450v` (or a comma list) to build a
subset. The release PDF/QC/labels are built once, for the default variant (or
the single `--variant` if given).

After a multi-variant run, the root also gets:

- `Variant_Comparison.md`: per-variant totals plus "only in X" and
  quantity-difference tables with vendor PN/price columns.
- `variants.json`: machine-readable manifest (names, descriptions, output
  dirs, added/removed designations, line counts, totals). HWRelease copies
  both into chassis releases and lists the variant names as
  `build_variants` in the release manifest.

Both stay tracked in git alongside `Pricing_Report.md`; everything else under
`Builds/` is gitignored. Note the two "variants" concepts live in different
places: **build variants** (parts differ) under `FabricationData/Builds/`,
**spares tiers** (only quantities differ) under `FabricationData/BOMs/Variants/`.

## Importing real prices back

After carts/orders exist, import them; prices land in the local cache **and**
the committed part database (so cost history survives a fresh clone):

```text
import mouser ~/Downloads/mouser_bom.xlsx    # BOM-tool xlsx or pasted text
import digikey ~/Downloads/digikey.csv.xlsx  # BOM-tool export
import mcmaster                              # paste order text, Ctrl+D
import jlcpcb                                 # paste cart text (per-board fab prices)
import sendcutsend                            # paste cart text (fills info.txt)
```

The Mouser importer also resolves parts you uploaded by manufacturer PN and
writes the resolved Mouser PNs back into the database, so the next upload is
fully populated. Unmatched lines are reported, not silently dropped.

## Revisions

```text
rev list
rev bump DCLBB --note "widen mounting holes"
```

- Internal PNs (`HW-C2-BB-DCLBB-A`) are identity-keyed; editing descriptions
  or friendly names never renumbers anything.
- Bumping writes `Rev=` into a fab part's `info.txt` and records history
  (rev, date, note) in `Numbers.json`. **Folders and files are never
  renamed**, so CAD and vendor links keep working.
- For PCBs, the rev on the silkscreen is yours to maintain: bump in the tool
  and update the silk text in the same sitting, so boards say what they are.
- When you bump, re-export vendor-facing artifacts (STEP, PDFs) with the new
  rev in the filename.

## Regen: change the design, run one command

```text
regen
```

re-exports everything from KiCad and rebuilds the BOM:

- each board: BOM CSV (`sch export bom`), gerbers + drill into `Fab/`,
  board STEP model, and a DRC report at `FabricationData/DRC/<Board>.txt`
  (**errors only**; warnings are suppressed for now; counts printed per board)
- each harness: BOM CSV from its schematic
- then a normal `generate` runs

The loop is: edit schematics/layout in KiCad → `regen` → order/check the
outputs. `release` afterwards for the PDF + assembly HTML.

## The release PDF

`release` also builds `FabricationData/Release_Report.pdf` (styled after the
project docs, same format as `Docs/HARA.pdf`):

- Cover with totals and the 1/2/3/5/10-unit scaling table
- Contents page, order summary (per-vendor tables, pack-aware)
- Fabrication package (readiness incl. harness qty/rev + a page per fab part
  with a **fresh 3D preview rendered from its STEP file**, colored by material)
- Per board: divider (name, IPN, **3D board renders** top + bottom) →
  **composite front/back views** (the PCB-viewer look: copper + silk + mask)
  → full schematic → PCB layer plots (all copper + silkscreen, drawing sheet
  shows the true plot scale) → **DRC summary page** (errors only, from the
  regen reports)
- Per harness: divider → schematic
- **Design documents**: every document in `Docs/` (HARA, TARA, SWAD, Manual,
  analyses) is a part with its own IPN (`HW-C2-DOC-...`), compiled into the
  package: the PDF you ship with the device.

**Labels**: `FabricationData/Labels.pdf` (or `label` to regenerate alone):
two high-voltage warning labels, a chassis ID label (serial/date/inspector),
and a grid of per-assembly labels in the `InverterGen5 C2` convention
(name, IPN, rev, qty).

**Document standard: all project docs are Markdown** (`Docs/*.md`) compiled by
one template (docgen: cover page, auto-TOC with page numbers, footers, green
HARA style). Edit the `.md`, run `release`, and both `Docs/*.pdf` and the
package pick it up. No HTML, no LaTeX (use Unicode: ×, Δ, ρ, µ, °).

Rendering: board 3D renders and layer plots come from KiCad CLI (flatpak via
`flatpak run --command=kicad-cli org.kicad.KiCad`); fab-part previews are
rendered from STEP with cadquery + matplotlib (no GL needed); documents are
compiled with weasyprint. `bom.py` automatically re-executes itself with the
bundled `.venv` python when one exists, so dependencies always resolve.

## Assembly HTML (iBOM)

`release` also writes `FabricationData/Assembly/<Board>.html` per board: an
interactive assembly view (click a BOM line to highlight its parts on the
board, front/back views). Open in any browser; great for hand-stuffing.

## Cost by assembly & QC forms

The release PDF's **Cost by Assembly** section breaks the BOM down per
sub-assembly (each board, each harness, each fab part, chassis hardware) with
parts counts and per-assembly cost.

`FabricationData/QC_Forms.pdf`: one printable page per sub-assembly: header
(IPN, rev, qty per chassis), a checkbox parts list with per-assembly
quantities, an inspection checklist (per assembly kind), and a
sign-off block (assembled / inspected / signatures) for the assembler.

## Data files

Committed: `Database.json` (PNs, pack sizes, prices), `Numbers.json`
(IPNs + revision history), `Descriptors.json`, `MechanicalBOM.txt`,
fab part folders, harness folders.

Gitignored (local): `Config.yaml`, `PriceCache.json`, `Inventory.json`
(your shelf stock).

## Command cheat sheet

```text
status | parts [--missing|--unpriced|--vendor X|--type Y] [query]
add | price <q> <usd> | pack <q> <size> [price] | stock [q] [n]
mech [add <vendor> <pn> <qty> [desc] | set <pn> <qty> | rm <pn>]
new fab|harness|board [name]
rev list | rev bump <q> [--rev X] [--note "..."]
fab | fab pcb-price <board> <usd>
import mouser|digikey|mcmaster|sendcutsend|jlcpcb [file]
generate [--qty N --spares none|cheap|all --chassis X --no-prompt]
release
exclude <q> | include <q> | forget <q> | chassis [name] | quit
```

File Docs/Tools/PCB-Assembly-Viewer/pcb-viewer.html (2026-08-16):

OpenVVVF

# OpenVVVF/PCB Assembly Viewer

Select a PCB on the left.

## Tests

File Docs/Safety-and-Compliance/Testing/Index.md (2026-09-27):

---
doctype: Index
doc_id: OV-TEST-INDEX
title: Testing and Validation
product_line: openvvvf
applies_to:
  - openvvvf-control-module
  - chassis-size-2
version: "1.1"
date: "2026-09-27"
description: Formal test reports and validation evidence for OpenVVVF hardware, firmware, and integration.
nav_order: 340
---

# Testing and Validation

This section contains formal test records and validation evidence. Each document is evidence that a specific feature, requirement, or hazard mitigation was exercised.

All hardware power tests follow the shared definitions and evidence requirements of the [Hardware Test Methodology](Test-Methodology/Index.md) — steady-state criteria, calculated quantities (P/Q/PF/efficiency), reconciliation rules, and naming.

## Test evidence dashboard

### Hardware

| Test ID | Name | Motor class | Status | Trace | Report |
|---|---|---|---|---|---|
| 1 | PMSM Resistance Calibration Validation | PMSM | draft | motor self-commissioning / calibration routine | [Report](Hardware/PMSM-Motor-Calibration/Resistance/Index.md) |
| 2 | PMSM Inductance Calibration Validation | PMSM | draft | motor self-commissioning / calibration routine | [Report](Hardware/PMSM-Motor-Calibration/Inductance/Index.md) |
| 3 | Power Resistor Sanity Check | - | draft | motor self-commissioning / calibration routine | [Report](Hardware/PMSM-Motor-Calibration/Resistor-Sanity-Check/Index.md) |
| 4 | Induction Motor Testbed | Induction | draft | motor self-commissioning / calibration routine | [Report](Hardware/Induction-Motor-Calibration/Testbed/Index.md) |
| 5 | Induction Motor Resistance Calibration Validation | Induction | draft | motor self-commissioning / calibration routine | [Report](Hardware/Induction-Motor-Calibration/Resistance/Index.md) |
| 6 | Inductance Calibration Validation | Induction | draft | motor self-commissioning / calibration routine | [Report](Hardware/Induction-Motor-Calibration/Inductance/Index.md) |
| 7 | Induction Motor 1-Hour No-Load Test | Induction | draft | gate-driver switching / thermal baseline | [Report](Hardware/Induction-Motor-No-Load-Test/Index.md) |
| 8 | Induction Motor 180 V Power Stage Bring-up | Induction | draft | power-stage bring-up at elevated bus voltage | [Report](Hardware/Induction-Motor-180V-Bringup/Index.md) |
| 9 | Induction Motor 180 V 20-Minute Reversal Test | Induction | draft | direction-change sequencing / current control | [Report](Hardware/Induction-Motor-180V-Reversal/Index.md) |
| 10 | Motor Self-Commissioning Accuracy Report | PMSM + Induction | draft | motor self-commissioning / calibration routine | [Report](Hardware/Motor-Self-Commissioning-Accuracy/Index.md) |
| 11 | Gen7 Board Temperature Sensor Validation | - | draft | board temperature sensing / ADC measurement chain (OV-TEST-HW-GEN7-TEMP-NTC-VALIDATION) | [Report](Hardware/Gen7-Temp-Sensor-Validation/Index.md) |
| 12 | Low-Power Regen 100 A Phase-Current Endurance (No Cooling) | Induction | draft | high-current regen endurance / phase-current capability at low DC-bus voltage (no cooling) | [Report](Hardware/Low-Power-Regen-100A-No-Cooling/Index.md) |
| 13 | 200 A Regen to 79 °C — Gen7 Size 2 | Induction | draft | high-current regen staircase; thermal rise with dry heatsink interface | [Report](Hardware/Low-Power-Regen-200A-Gen7-Size2/Index.md) |
| 14 | Thermal OTP Trip — 200 A Regen, Gen7 Size 2 | Induction | draft | overtemperature protection chain validation (trip at ~80 °C baseplate) | [Report](Hardware/Thermal-OTP-200A-Gen7-Size2/Index.md) |
| 15 | Initial 400 A Regen Test — Gen7 Size 2 | Induction | draft | 400 A phase-current capability with bus clamp; current-clamp saturation identified as measurement artifact | [Report](Hardware/Low-Power-Regen-400A-Gen7-Size2/Index.md) |
| 16 | 450 A / 13 kW Regen — Gen7 Size 2 | Induction | draft | 450 A phase-current capability at ~150 V clamp; OT trip reproduced | [Report](Hardware/Low-Power-Regen-450A-Gen7-Size2/Index.md) |
| 17 | 200 A Regen Steady-State Thermal Test — Gen7 Size 2 | PMSM | draft | continuous-duty validation of the thermally-pasted interface (54.7 min, plateau 44.4/44.0 °C) | [Report](Hardware/Low-Power-Regen-200A-Steady-State-Gen7-Size2/Index.md) |
| 18 | 200 A Motoring Steady-State Thermal Test — Gen7 Size 2 | PMSM | draft | motoring-direction counterpart of test 17 (42 min, plateau 43.6/43.5 °C) | [Report](Hardware/Low-Power-Motoring-200A-Steady-State-Gen7-Size2/Index.md) |
| 19 | 300 A Regen Steady-State Thermal Test — Gen7 Size 2 | PMSM | draft | 300 A continuous regen at ~2,600 RPM (22.9 min, 11.7 kW, plateau 63.2/61.7 °C; stopped on machine limit) | [Report](Hardware/Low-Power-Regen-300A-Steady-State-Gen7-Size2/Index.md) |
| 20 | SSO Pathway Latency — Gen7 Size 2, Low Bus | PMSM | draft | fault→six-switch-open latency (SG-03/SG-13, FSR-05): gate-driver fault ≤10 ms bound; ADC watchdog ISR break, bounded 30.3 A trip; physical pathways deferred | [Report](Hardware/SSO-Latency-Gen7-Size2/Index.md) |
| 21 | SSO Gate-Drive Kill Pathways — Gen7 Size 2, Low Bus | PMSM | draft | Path 2a gate-power kill + Path 4 reset assertion (SG-03/SG-13, FSR-05): as-found no detection, gate-loss + TorqueLoss detectors added, retested to pass (flags ≤0.3 s) | [Report](Hardware/SSO-GateKill-Gen7-Size2/Index.md) |
| 22 | Over-Torque Watchdog — 55 A Trip, Locked Rotor, Gen7 Size 2 | PMSM | draft | SG-06/FSR-07: 110 %-of-calibrated-max over-torque chain implemented fix-forward; trip at 55.0 A vs 50 A max, 3× repeatable, SSO ≈0.6 ms, derived AWD backstop | [Report](Hardware/Overcurrent-Watchdog-55A-Gen7-Size2/Index.md) |
| 23 | Rotor Feedback Loss Detection — Gen7 Size 2, Low Bus | PMSM | draft | SG-08/FSR-09: hard sin/cos disconnect at −2190 RPM → SSO µs–10 ms via all-channel AWD; blind-start defect fixed (start refusal), Critical EncoderLoss chain added; layered detection documented | [Report](Hardware/Encoder-Loss-Gen7-Size2/Index.md) |
| 24 | DC-Link OV/UV Protection — Threshold Injection, Gen7 Size 2 | PMSM | draft | SG-10/FSR-11/FSR-21: all four transitions validated at 49 V by threshold injection; OV-warning regen-disable + UV derate implemented fix-forward; critical OV/UV SSO ≪50 ms; FSR-21 candidate thresholds recorded | [Report](Hardware/DCLink-OVUV-Gen7-Size2/Index.md) |
| 25 | DESAT / Gate-Driver FLT Protection — Pulse Injection, Gen7 Size 2 | PMSM | draft | SG-12/SG-14/FSR-13: 50 V ≥800 A no-DESAT bound; 100 V winding pulses → driver /FLT; FLT→MCU blindness (missing BIE/NVIC) fixed, latched PwmBreak + SSO verified; coproc FLT path open | [Report](Hardware/Desat-Short-Circuit-Gen7-Size2/Index.md) |

These reports validate the calibration routines on the C2 test fixture. The same routines are used on all OpenVVVF chassis; add a new report only when a different motor or harness is introduced.

### Safety-mechanism validation

| Test ID | Name | Scope | Status | Trace | Plan |
|---|---|---|---|---|---|
| - | Fault-Injection Test Plan | component / system / integration / environmental fault injection (control module + power stage) | planned | HARA safety goals, FSRs, hazards | [Plan](Fault-Injection-Test-Plan/Index.md) |
| - | Vibration Test Plan | mechanical/environmental random vibration (control module + C2 power stage assembly) | planned | HARA failure modes relying on connectors/harness; fault-injection E-01 | [Plan](Vibration-Test-Plan/Index.md) |
| - | Thermal Test Plan | hardware thermal characterization + firmware thermal behavior (FSR-08 derate/SSO), C2 power stage | planned | OV-C2-DD-THERMAL, OV-C2-DD-DCLINK-THERMAL, FSR-08 | [Plan](Thermal-Test-Plan/Index.md) |

The fault-injection plan spans all test domains, so it is filed directly under Testing. Execution campaigns produce dated test reports filed as siblings of the plan, referencing it by test ID.

## Domains

Documents are filed by **what is being tested**, not by what equipment the bench uses:

- **Hardware** - The DUT is physical hardware: power-stage bring-up, thermal, and bench characterization. Firmware-routine validations whose error budget is power-stage physics (e.g. motor self-commissioning calibrated against instruments) also live here.
- **Firmware** - The DUT is control-module firmware logic: unit tests and host- or bench-based tests that do not inject physical faults.
- **Integration** - System-level tests combining control module and power stage.

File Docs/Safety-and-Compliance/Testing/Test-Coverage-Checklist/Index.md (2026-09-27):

---
doctype: Test Plan
doc_id: OV-TEST-COVERAGE
title: HARA Test Coverage Checklist
product_line: openvvvf
applies_to:
  - openvvvf-control-module
  - chassis-size-2
version: "0.8"
date: "2026-09-27"
description: Maps every HARA safety goal (OV-SAF-HARA-CORE v5.10, motorcycle profile v1.8) to its validation evidence and gaps. Completed power/thermal tests (7–19) are indexed by safety goal; every remaining gap names the required test and, where a plan stub exists, its doc_id. The working checklist for deciding what to test next.
nav_order: 381
normative_refs:
  - OV-TEST-INDEX
  - OV-TEST-METHODOLOGY
  - OV-SAF-HARA-CORE
  - OV-SAF-HARA-PROF-MOTO
  - OV-TEST-FAULT-INJECTION
  - OV-TEST-THERMAL-PLAN
placeholder: true
---

# HARA Test Coverage Checklist

Status of each safety goal in [OV-SAF-HARA-CORE](../../HARA/Core/Index.md) v5.10 (motorcycle profile [OV-SAF-HARA-PROF-MOTO](../../HARA/Application-Profiles/Motorcycle/Index.md) v1.8 ASIL targets) against the completed hardware tests (test IDs 7–19) and the fault-injection / thermal plans. Methods referenced throughout are defined in [OV-TEST-METHODOLOGY](../Test-Methodology/Index.md).

**Statuses:** ✅ covered · ◐ partial evidence · ○ open · ⛔ blocked on unimplemented firmware.

**SG numbering note:** H-11/SG-11 were removed in HARA v5.4 (HV contactor is BMS/OEM domain); goals run SG-01…SG-10, SG-12…SG-15.

## Coverage matrix

| SG | ASIL | Mechanisms (FSRs) | Existing evidence | Status | Required action |
|----|---|---|---|---|---|
| SG-01 Unintended positive torque | D | FSR-01 dual throttle 1oo2 (>5 % → SSO), FSR-18 limit switch <50 ms, FSR-03 rate limit 500 Nm/s, FSR-02 plausibility, FSR-17 CAN heartbeat, FSR-19 boot CRC | None | ○ | Fault-injection campaign C-01–C-06, C-13, C-14, C-20, C-23–C-25, C-39, C-41, S-01/S-02, I-01–I-03, I-06–I-08, I-11, I-15–I-17 (per [OV-TEST-FAULT-INJECTION](../Fault-Injection-Test-Plan/Index.md)). ⛔ Several FSRs still Planned (below) |
| SG-02 Unintended reverse torque | B | FSR-04 reverse interlock (>100 rpm → clamp) | None | ⛔ | FSR-04 firmware Planned → implement, then FI tests S-02, S-14, C-13, I-13 |
| SG-03 Loss of torque → safe state ≤200 ms | C | FSR-05: six SSO pathways (TIM1_BKIN <100 ns; 1oo2 power kill ~10 µs; rail-loss passive; GATE_DRIVE_RESET <1 µs; watchdog ~100 ms; coprocessor trigger <10 µs) | ◐ OTP trips (tests 14, 16) via firmware FAULT state. **Test 20** (2026-09-26, [report](../Hardware/SSO-Latency-Gen7-Size2/Index.md)): gate-driver fault → SSO ≤10 ms telemetry-bound; ADC watchdog (TIM1_BKIN) → SSO with ISR-immediate break, bounded 30.3 A, correct flags, re-enable blocked. **Test 21** (2026-09-26, [report](../Hardware/SSO-GateKill-Gen7-Size2/Index.md)): Path 2a gate-power kill and Path 4 GATE_DRIVE_RESET exercised through the real enable/reset lines — as-found empty flag word, fixed (gate-loss + TorqueLoss detectors), retested to pass with single-bit flags in ≤0.3 s; 4 of 6 pathways now have low-bus evidence | ◐ | Still open: Path 2b + Paths 5/6 (coprocessor firmware in progress), Path 3 3.3 V rail (needs rig) per [OV-TEST-HW-SSO-LATENCY](../Hardware/SSO-Latency/Index.md); then FI C-13/C-14/C-22, S-03/S-04, S-10–S-13, S-16–S-19 |
| SG-04 Loss of regen detection | A | Monitoring + CAN indication (GAP-TEST-01: no dedicated test exists) | None — regen runs prove regen works, not its loss | ○ | [OV-TEST-HW-LOSS-OF-REGEN](../Hardware/Loss-Of-Regen/Index.md) stub |
| SG-05 Unintended regen → safe state | C | FSR-06 uncommanded-regen monitor | None | ⛔ | FSR-06 firmware Planned → implement, then FI S-05, S-08, S-17, I-14 |
| SG-06 Over-torque limit (>110 % → SSO <100 ms) | C | FSR-07 torque-limit LUT cross-check; analog watchdog OCP **10 µs**; DESAT <2 µs | ◐ Tests 15/16 show clean commanded current to 470 A (no false trips). **Test 22** (2026-09-26, [report](../Hardware/Overcurrent-Watchdog-55A-Gen7-Size2/Index.md)): over-torque chain implemented fix-forward (calibrated `Motor.MaxTorqueCurrentA`, 110 % monitor with ISR break + derived AWD backstop) — trip at 55.0 A vs 50 A max, repeatable 3×, SSO ≈0.6 ms, latched flags, clean recovery, locked rotor at 49 V; main-MCU element done, coproc dual-MCU element open | ◐ | Coprocessor dual-MCU half of FSR-07 (colleague's firmware); ratify production calibrated max from power series then re-set config; FI C-06/C-07/C-41, S-09, S-15; DESAT <2 µs via [OV-TEST-HW-DESAT-SHORT](../Hardware/Desat-Short-Circuit/Index.md) |
| SG-07 Over-temperature derate + safe state | B | FSR-08: 2 IGBT NTC 1oo2 + 1 cap NTC; **derate 90 °C; SSO 105 °C cap channel**; 100 °C IGBT-module hard cap; thresholds in ECC | ◐ **Actuation chain proven in-circuit** by tests 14/16 (IGBT baseplate NTC → FAULT `0x04000000` (`OvertemperatureInverter`) → immediate gate cut at full phase current — claimed as actuation evidence). Tests 12, 13, 17–19: steady-state thermal data below derate. Caveats: trip was ~80 °C on the IGBT channel (≠ FSR-08 thresholds), latency never measured, derate never crossed, cap channel never heated | ○ | Actuation artifact: **claimed from tests 14/16** (no reheating needed). Remaining: [OV-TEST-HW-THERMAL-FSR08-THRESHOLDS](../Hardware/Thermal-FSR08-Thresholds/Index.md) stub — externally heated run for the 90 °C derate, 105 °C cap-channel SSO, 100 °C module cap, ECC read-back, and ~80 °C reconciliation (per Thermal plan T-06). ⛔ 1oo2 voter Planned |
| SG-08 Rotor feedback loss → safe state <100 ms | C | FSR-09 encoder-loss detection (<50 ms target per LIMIT-04) | **Test 23** (2026-09-26, [report](../Hardware/Encoder-Loss-Gen7-Size2/Index.md)): hard sin/cos disconnect at −2190 RPM → SSO in µs–10 ms via all-channel AWD (ISR break), encoder flag latched, blocked re-enable; as-found blind-start defect fixed (start refusal on invalid feedback) + Critical EncoderLoss chain (bit 33) for in-window degradation; TorqueLoss net validated live | ◐ | FI C-09, C-28–C-30 (partial/degraded feedback); amplitude-collapse debounce (~250 ms) tightening for the 100 ms budget on that mode; optional scope-timed latency capture |
| SG-09 HV isolation >500 Ω/V | A | HVIL <50 ms (FSR-10); >5 kVrms reinforced per gate-driver channel | None | ○ | FI C-50 (1 kV applied-leakage method), I-04 — external-lab territory; bench keeps clear |
| SG-10 DC-link OV/UV | B | FSR-11 isolated ADC bus monitor; OV → regen disable; critical OV → SSO <50 ms; FSR-21 UV (thresholds undefined) | **Test 24** (2026-09-26, [report](../Hardware/DCLink-OVUV-Gen7-Size2/Index.md)): all four transitions validated at 49 V by threshold injection — OV warning regen-disable + UV derate implemented fix-forward (bits 34/35), critical OV/UV comparator path SSO ≪50 ms, candidate FSR-21 thresholds recorded (derate 40 V, critical 30 V); 450 V-class + bus dynamics open | ◐ | 450 V-class execution with bus controller (load-bank ramp, OV overshoot/UV ride-through vs link capacitance); FSR-21 ratification of candidate thresholds |
| SG-12 Shoot-through prevention <10 µs | C | FSR-12 complementary inputs (no ASIL credit); FSR-13 DESAT 6.5 V <2 µs, soft turn-off, Miller clamp, UVLO 12.2/11.3 V | **Test 25** (2026-09-27, [report](../Hardware/Desat-Short-Circuit-Gen7-Size2/Index.md)): full-duty winding pulses at 50/100 V — 50 V ≥800 A no DESAT (below 6.5 V knee, negative bound); 100 V 2/5 ms → driver /FLT; hardware BKIN path proven (MOE drop + BIF at hardware speed) after fixing missing BIE/NVIC plumbing; soft turn-off/Miller/UVLO and scope-measured figures open | ◐ | Scope-measured <2 µs/<10 µs, soft turn-off + Miller clamp + UVLO 12.2/11.3 V characterization; bolted-short µs-regime fixture; FI C-15–C-17, C-26, C-27, C-31–C-34 |
| SG-13 Safe state ≤200 ms, independent of control loop | D | Six SSO pathways; FSR-14 breakpoint <10 µs; FSR-15 watchdog ≤50 ms + challenge/response; FSR-16 POST; FSR-19 boot CRC; FSR-22 codegen FFI | ◐ Same OTP-trip note as SG-03. **Test 20** (2026-09-26, [report](../Hardware/SSO-Latency-Gen7-Size2/Index.md)): ADC-watchdog SSO asserts the TIM1 break in the watchdog ISR, independent of the main control loop; gate-driver fault path SSO ≤10 ms telemetry-bound. **Test 21** (2026-09-26, [report](../Hardware/SSO-GateKill-Gen7-Size2/Index.md)): gate-power kill + reset assertion detected via supervisor-independent observables (/RDY pin, torque-loss signature) with latched single-bit flags; control loop cannot prevent the safe state (both cuts are passive at the gate end) | ◐ | Coprocessor independence paths (5/6, FSR-15 challenge/response) still open per [OV-TEST-HW-SSO-LATENCY](../Hardware/SSO-Latency/Index.md); then FI C-13–C-17, C-19–C-25, C-43, S-01–S-03, S-10–S-12, I-04. ⛔ FSR-16/19/22 incomplete |
| SG-14 Gate-driver fault (DESAT/UVLO/TSD) → safe state | C | OR'd FLT to both MCUs (TIM1_BKIN + coprocessor GPIO cross-check) | **Test 25** (2026-09-27, [report](../Hardware/Desat-Short-Circuit-Gen7-Size2/Index.md)): as-found FLT→main-MCU chain fully blind (BIE + NVIC never enabled, no GPIO poll) despite a correctly wired BKIN path; fixed — latched Critical PwmBreak `0x00000002` + SSO on real 100 V DESAT events, recovery verified; coproc FLT path open (colleague) | ◐ | Coprocessor /FLT cross-check (colleague's firmware); FI C-15–C-17, C-26, C-27, C-31–C-34 |
| SG-15 Deadtime / stuck-on detection >100 µs → safe state | C | Coprocessor PWM-pair monitor; FSR-20 ECC (mapped here in Core Table 8) | None | ○ | FI C-15, C-16, C-49 (coprocessor bench); no dedicated hardware stub yet |

## Chassis-variant coverage

Continuous-duty thermal validation exists only for the **200 V class** (tests 17–19; variant matrix in OV-TEST-METHODOLOGY §6). The **450 V class** column is empty: [OV-TEST-HW-STEADY-STATE-450V](../Hardware/Steady-State-450V/Index.md) is the fill-in stub for the equivalent staircase/hold campaign. Ceiling/floor variants (voltage, temperature, switching frequency) are reserved per the methodology scope note.

## Firmware implementation gaps blocking test (FSRs not implemented)

These cannot be *verified* until implemented; they are the gating items for the ⛔ rows above.

| FSR | Item | Status |
|-----|---|---|
| FSR-02 | Command-vs-measured current plausibility (>20 % / >100 ms) | Planned |
| FSR-04 | Reverse interlock (>100 rpm clamp) | Planned |
| FSR-06 | Uncommanded-regen monitor | Planned |
| FSR-08 voter | 1oo2 temperature voting | Planned |
| FSR-16 | POST before PWM enable | Partial |
| FSR-17 | CAN safe defaults on heartbeat loss | Planned |
| FSR-19 | Boot CRC-32 (GAP-SW-01, P1) | To implement |
| FSR-21 | UV thresholds (SG-10) | Planned |
| FSR-22 | Generated-code fault cases (GAP-SW-04, P1) | Planned |

## Other explicit HARA open items (not bench stubs)

- **DFA (LIMIT-08, P0)** — no dependent-failure analysis; blocks any ASIL D claim on SG-01/SG-13.
- **LIMIT-01 / H-03a** — track characterization of abrupt torque-loss controllability (accepted residual risk).
- **EMC pre-compliance (LIMIT-09, P1)** — CISPR 25 pre-scan; E-08/E-09 external lab.
- **E-series environmental type tests (E-01…E-12)** — deferred; vibration/shock/thermal-soak/humidity/ESD/ingress (see [Vibration Test Plan](../Vibration-Test-Plan/Index.md) and [Thermal Test Plan](../Thermal-Test-Plan/Index.md)).
- **Hardware architectural metrics** — no FMEDA/SPFM/LFM yet; decomposition remains design-stage.
- **FI plan v1.1 execution** — all 80 C/S/I tests Defined, none Executed; this checklist's stub column is the hardware-executable priority subset.

## How to use this checklist

1. Pick the highest-ASIL open row with an unblocked mechanism (SG-13/SG-03 SSO latency is the natural next hardware test).
2. Open the referenced stub (or FI-plan entry), fill the `[FILL]` execution parameters for the chassis variant under test (200 V / 450 V), run per [OV-TEST-METHODOLOGY](../Test-Methodology/Index.md).
3. Execute, file the dated Test Report as a sibling of the stub, link it here and in the [test evidence dashboard](../Index.md), and flip the row status.
4. A row may only be marked ✅ when the quantified budget in its mechanisms column is demonstrated in the report (e.g. SSO ≤200 ms measured, not assumed).

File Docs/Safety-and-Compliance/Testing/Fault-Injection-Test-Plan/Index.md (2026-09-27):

---
doctype: Test Plan
doc_id: OV-TEST-FAULT-INJECTION
title: Fault Injection Test Plan
product_line: openvvvf
applies_to:
  - openvvvf-control-module
  - chassis-size-2
version: "1.2"
date: "2026-09-25"
description: Safety-mechanism validation by fault injection across component, system, and integration levels; exercises the control module and the C2 power stage as one test article. Extracted from the HARA Core document.
nav_order: 371
normative_refs:
  - OV-SAF-HARA-CORE
---

This document is the fault-injection test plan for the OpenVVVF control module. It was extracted from the HARA Core document ([OV-SAF-HARA-CORE](../../HARA/Core/Index.md)) at its version 5.7, where it was Section 10; internal cross-references have been adapted to this document's headings. References to other section numbers (e.g., Section 2.3) refer to OV-SAF-HARA-CORE.

This plan is filed directly under `Testing/` rather than under a domain folder because its categories span all of them: the mechanisms under test are firmware safety functions, but the stimulus is physical fault injection into control-module and power-stage hardware (C-series), the closed-loop system (S-series), and external interfaces (I-series). Test execution records and evidence are maintained separately per the evidence framework defined herein: each execution campaign produces a dated `Test Report` document filed as a sibling of this plan, referencing it by doc_id and test ID. Evidence reports are immutable once released; this plan's status tables are the living roll-up.

# Fault Injection Test Plan

## Test Philosophy

The purpose of this Fault Injection Test Plan is to provide a comprehensive, traceable methodology for verifying that the safety mechanisms implemented in the control module detect faults and transition to the defined safe state (immediate SSO, Section 2.3) within the required time budgets. The test plan defines **80 tests** organized into three categories, plus 12 deferred environmental test stubs in a fourth:

- **Component-Level Tests (43 tests, numbered C-01 to C-50 with gaps):** Individual hardware component validation - inject faults into a single sensor, input, or protection circuit and verify detection and safe state entry.
- **System-Level Tests (S-01 to S-19):** Full-system fault scenarios with the complete hardware and software running closed-loop control.
- **Integration-Level Tests (I-01 to I-18):** External interface and communication fault scenarios (DC source management node, IO board, CAN bus).
- **Environmental Tests (E-01 to E-12):** Environmental and stress type tests. **The entire E-series is deferred** - the project does not currently have access to an environmental chamber, vibration table, EMC chamber, ESD gun, or water spray rig. The E-series is retained as a stub reference plan (Environmental and Stress Tests (E-Series) - DEFERRED) for a future type-test campaign and shall not be cited as covering any Safety Goal, FSR, or hazard in the current campaign.

Each test case is designed with the following principles:

1. **Every Safety Goal (SG-01 through SG-15; SG-11 removed in HARA v5.4) is covered by at least one test case** that is executable with available equipment.
2. **Every Functional Safety Requirement (FSR-01 through FSR-22) is covered by at least one executable test case** (FSR-22 coverage is planned as generated-code fault cases per GAP-SW-04 and is not yet elaborated).
3. **Every identified hazard (H-01 through H-17, including H-03a; H-11 removed in HARA v5.4) is covered by at least one executable test case** at the drive-boundary level; vehicle-level validation limits are documented in Known Test Limitations.
4. **Response time requirements shall be verified** where measurable (e.g., <10 us HW PWM disable, ≤50 ms WDT timeout, ≤200 ms detection-to-SSO).
5. **Fault injection shall be realistic** - faults represent credible failure modes observed in traction power electronics systems.
6. **Tests shall be independently executable** where possible to allow incremental validation as software matures.
7. **Only tests that can actually be executed with available equipment are scheduled in the current campaign.** Each test carries an explicit executability status (Test Status Summary).

### Test Status Vocabulary

The following vocabulary shall be used consistently for every test and requirement:

| Term | Meaning |
| --- | --- |
| **Defined** | Test procedure and acceptance criteria written; not yet executed. |
| **Executable** | All required equipment and facilities are available; the test can be run in the current campaign. |
| **Conditional** | Executable subject to a stated minor prerequisite (e.g., a small LV bench supply). |
| **Deferred** | Cannot be executed with available equipment or facilities; scheduled for a future campaign or external lab. |
| **Executed** | Test has been run; raw evidence (telemetry, scope captures) recorded per Test Records and Evidence. |
| **Verified** | Executed, passed, and reviewed; evidence reference entered in the traceability matrices. |

### Statement on Execution Records

> This section **defines** the fault injection test plan and acceptance criteria. Test execution records, measured results, telemetry logs, and scope-capture evidence shall be maintained separately in the OpenVVVF verification evidence repository and summarized in the OpenVVVF Verification Report(s). This document shall be updated only to reflect changes to the plan itself. As of this revision, all tests are **Defined**; none are **Executed** or **Verified**.

## Test Environment

### Available Test Equipment

The following equipment is **available** for the current campaign. Tests requiring anything not on this list are marked Conditional or Deferred.

**Table 11 - Available Test Equipment**

| Item | Description | Used For |
| --- | --- | --- |
| **Test article** | Control module PCB with STM32H723 + STM32G474, six NCV57100, IGBT power stage (200 V class board; testing limited to ≤175 V DC, nominal 140 V), all sensors | Device under test (DUT) |
| **DC link source** | Programmable bidirectional DC supply, 0–1500 V DC, −50 A to +50 A (current-limited; provides both sourcing and sinking for regen tests) | DC link for all power tests; energize-into-fault short tests |
| **Dyno** | 4-quadrant motor dynamometer with speed and torque measurement and programmable load | All load tests, regen tests, full-load characterization |
| **Test motor** | Low-voltage PMSM on dyno | Closed-loop traction motor control testing |
| **Oscilloscope** | 4-channel, with HV differential probes and current probes | Timing verification of PWM disable, DESAT response, gate signals, deadtime |
| **CAN interface** | USB-CAN adapter (PCAN or equivalent) | CAN traffic monitoring, CAN node simulation (source management, IO board, charger, ABS, display), fuzzing |
| **Debug probe** | ST-Link / J-Link with halt and memory access | CPU-halt fault injection (C-13), ECC/flash corruption (C-18–C-20, C-39) |
| **Throttle simulation** | Two programmable DC supplies feeding the throttle wiper inputs | C-01–C-04, S-01 (method note, Component-Level Tests) |
| **Thermal camera** | Infrared camera | Full-load thermal survey (S-06), hotspot identification, post-short inspection |
| **Heat gun** | Localized heating of NTC sensors | C-08, C-35 (simulated over-temperature) |
| **RTE (Real Time Examiner)** | Host tool connected via CAN or debug interface | Internal variable monitoring, tractive effort commands, fault status |

### Equipment Not Available (Drives Deferred Status)

| Item | Consequence |
| --- | --- |
| Insulation tester (megohmmeter) / HiPot tester | C-50 uses the alternative applied-voltage leakage method (see C-50 procedure). |
| Short-circuit contactor | C-31–C-34 use the energize-into-fault method: the short is bolted on de-energized, then the DC link is energized via the programmable supply at stepped voltage (see C-31 procedure). Mid-operation short injection is not performed; limitation documented in Known Test Limitations (LIMIT-10). |
| Small programmable LV bench supply (for 3.3 V / 12 V / 5 V rail wiggling) | C-21, C-22, C-24, C-25 are **Conditional** on availability of such a supply (the throttle-simulation supplies may serve if rated appropriately). |
| Thermal chamber, humidity chamber, vibration table, EMC chamber, ESD gun, water spray rig | E-01 through E-12 **Deferred** (type tests). |
| Shaft voltage / bearing-current brush rig | C-36 **Deferred** pending construction of the measurement fixture. |

### Test Records and Evidence

Every executed test shall produce the following evidence artifacts:

1. **Test report** - the written execution record (procedure as run, measured values, pass/fail against acceptance criteria), filed per the evidence framework defined in this document's introduction.
2. **Telemetry log** - RTE/CAN capture of internal variables, fault status, and tractive effort commands for the full test duration.
3. **Scope captures** - saved waveforms for every timing-critical measurement (PWM disable, DESAT response, deadtime, etc.).

Naming convention: `<TestID>_run<N>_<YYYY-MM-DD>_<condition>.<ext>`, e.g., `C-15_run2_2026-08-14_60V.csv`, with the telemetry log and scope captures sharing the same base name. Evidence references shall be entered into the per-test **Evidence** field and the traceability matrices (Safety Goal Traceability) upon execution. Evidence shall be published alongside this document in the project repository. Video recording is not required evidence; where the operator chooses to record video or photos, they are supplementary artifacts and shall not be cited as required evidence in the traceability matrices.

## Test Status Summary

**Table 12 - Executability Summary (v5.0 Campaign)**

| Block | Tests | Status |
| --- | --- | --- |
| Sensor/input faults | C-01–C-09 | **Executable** (throttle via DC supplies; temp via heat gun; manual injection) |
| DC link & HVIL | C-10–C-12 | **Executable** |
| MCU/safety-path faults | C-13–C-20, C-39, C-41, C-43 | **Executable** |
| LV rail faults | C-21, C-22, C-24, C-25 | **Conditional** - requires small programmable LV bench supply |
| Rail/gate-supply shorts | C-23, C-26, C-27 | **Executable** (current-limited fixtures; C-26/27 via energize-into-fault) |
| Phase faults (open) | C-28–C-30 | **Executable** (manual disconnect under load) |
| Phase faults (short) | C-31–C-34 | **Executable** via energize-into-fault at stepped voltage (50 V → 140 V max) |
| Cap temp / ADC / SPI / thermal runaway / deadtime | C-35, C-41, C-42, C-45, C-49 | **Executable** |
| Bearing current | C-36 | **Deferred** - requires shaft brush fixture |
| Isolation | C-50 | **Executable** via alternative 1 kV leakage method |
| System tests | S-01–S-19 | **Executable** (4-quadrant dyno, thermal camera available) |
| Integration tests | I-01–I-18 | **Executable** (CAN simulation) |
| Environmental tests | E-01–E-12 | **Deferred** - type tests; no environmental equipment available |

Counts: **75 Defined-Executable, 4 Defined-Conditional (C-21, C-22, C-24, C-25 - pending LV bench supply), 1 Deferred-equipment (C-36), 12 Deferred-type-test (E-series stubs).** Total 92 line items including the E-series stubs; 80 tests defined in the current plan (43 C-series + 19 S-series + 18 I-series).

## Component-Level Tests

**Method note - throttle simulation:** For C-01 through C-04 and S-01, the dual throttle potentiometer wipers shall be simulated by two programmable DC supplies (0–5 V, common ground with the DUT). This permits precise, repeatable discrepancy, drift, short-to-rail, and short-to-ground injection. This method simulates the wiper signal only; it does not exercise ratiometric behavior against the sensor 5 V rail (rail faults are covered separately by C-24). At least one test in the campaign (C-05) shall use the real mechanical throttle assembly including the end-travel limit switch so the end-to-end path through the physical connector is exercised.

**Method note - manual fault injection:** Open-circuit faults shall be injected by physically disconnecting the relevant wire or connector during operation (no relay rig is used in this campaign). Gradual-drift faults shall be injected by ramping or stepping the simulating DC supply. Actual injection timing shall be captured from the telemetry record and scope captures; exact repeatability of the injection instant is not required.

### C-01: Tractive Effort Control Potentiometer 1 Open Circuit

**Objective:** Verify FSR-01 - dual tractive effort control plausibility shall detect an open circuit on the primary channel.

**Covered:** SG-01 (ASIL D), FSR-01, H-01
**Status:** Executable - Defined | **Evidence:** -

**Procedure:**

1. Connect throttle simulation supplies (method note, Component-Level Tests) with both channels functional. System at key-on, traction motor not running.
2. Apply 50% tractive effort request via both channels (matched within 2%).
3. While maintaining input, open-circuit channel 1 (disconnect at PCB).
4. Observe system response via RTE and oscilloscope on PWM outputs.
5. Repeat with traction motor spinning at 50% rated speed under dyno load.

**Acceptance Criteria:** The system shall detect channel 1 out-of-range / discrepancy >5% within <100 ms and shall transition to SSO. No tractive effort shall be produced after the fault. The fault shall be logged with the correct DTC.

**Rationale:** An open circuit on one channel is a credible wiring failure. The dual-channel plausibility check (FSR-01) must detect the discrepancy and enter safe state before any unintended tractive effort can be commanded. Directly addresses H-01.

### C-02: Tractive Effort Control Channel 2 Shorted to +5 V

**Objective:** Verify FSR-01 - the plausibility check shall detect short-to-rail on the secondary channel.

**Covered:** SG-01 (ASIL D), FSR-01, H-01
**Status:** Executable - Defined | **Evidence:** -

**Procedure:**

1. Both channels functional. System at key-on.
2. Apply 25% request on channel 1; drive channel 2 to +5 V via the simulation supply (simulating wiring short).
3. Observe response via RTE and scope.
4. Repeat with traction motor running at 25% speed under load.

**Acceptance Criteria:** Discrepancy >5% shall be detected within <100 ms. Safe state shall be entered. Fault shall be logged.

**Rationale:** Short-to-rail is a common wiring fault (chafed harness). Distinct failure mode from C-01; verifies the plausibility check works for high anomalies.

### C-03: Tractive Effort Control Channel 1 Shorted to Ground

**Objective:** Verify FSR-01 - short-to-ground detection on the primary channel.

**Covered:** SG-01 (ASIL D), FSR-01, H-01
**Status:** Executable - Defined | **Evidence:** -

**Procedure:** Drive channel 1 to 0 V / ground while channel 2 is at 50%. Observe response. Repeat under motor load.

**Acceptance Criteria:** Discrepancy shall be detected within <100 ms. Safe state shall be entered. Fault shall be logged.

**Rationale:** Ground short is distinct from open and +5 V short (different ADC reading). Verifies robustness across all three common wiring fault modes.

### C-04: Tractive Effort Control Drift (Gradual Divergence)

**Objective:** Verify FSR-01 shall detect gradual channel mismatch (sensor degradation).

**Covered:** SG-01 (ASIL D), FSR-01, H-01
**Status:** Executable - Defined | **Evidence:** -

**Procedure:** Using the throttle simulation supplies, gradually increase the offset between channel 1 and channel 2 from 0% to 10% over 10 seconds while the traction motor runs at constant speed. Record the trip point from telemetry.

**Acceptance Criteria:** The fault shall trigger when discrepancy exceeds the 5% threshold. No false trips shall occur below threshold.

**Rationale:** Gradual drift (wear, aging) must be distinguished from normal variation. Verifies threshold calibration - neither nuisance trips nor missed faults.

### C-05: Tractive Effort Control Limit Switch Activation at Speed

**Objective:** Verify FSR-18 - the limit switch shall independently command zero tractive effort, overriding analog values.

**Covered:** SG-01 (ASIL D), FSR-18, H-01
**Status:** Executable - Defined | **Evidence:** -

**Procedure:** This test shall use the **real mechanical throttle assembly** (not the simulation supplies).

1. Traction motor running at 50% rated speed under dyno load with 50% tractive effort request applied.
2. Activate the tractive effort control limit switch (mechanical end-stop) while maintaining potentiometer position.
3. Observe tractive effort command and PWM output via RTE and scope.

**Acceptance Criteria:** The tractive effort command shall drop to zero within <50 ms of limit switch activation, regardless of potentiometer position. PWM shall be disabled or zero duty. Fault shall be logged.

**Rationale:** The limit switch is an independent hardware path to zero tractive effort - the last-resort protection against stuck cable or sensor malfunction. Also exercises the physical connector path end-to-end.

### C-06: Phase Current Sensor Offset Drift

**Objective:** Verify FSR-02 - tractive effort command plausibility shall detect current sensor offset error.

**Covered:** SG-01 (ASIL D), SG-06 (ASIL C), FSR-02, H-01, H-06
**Status:** Executable - Defined | **Evidence:** -

**Procedure:**

1. Traction motor running at 50% rated tractive effort under dyno load.
2. Inject DC offset (+20% of rated current) into one phase current sensor via external bias circuit.
3. Observe commanded tractive effort vs. measured current. Record the trip point.
4. Repeat with −20% offset.

**Acceptance Criteria:** Plausibility deviation >20% shall be detected within <100 ms. Safe state shall be entered.

**Rationale:** Sensor offset drift causes the MCU to misread actual current. Verifies the end-to-end plausibility chain (FSR-02).

### C-07: DC Link Current Sensor Open Circuit

**Objective:** Verify FSR-02 - loss of DC link current sensor shall be detected.

**Covered:** SG-01 (ASIL D), FSR-02, FSR-07, H-01, H-06
**Status:** Executable - Defined | **Evidence:** -

**Procedure:** Open-circuit the DC link current sensor signal wire while the traction motor runs at 25% load. Observe plausibility check and safe state entry.

**Acceptance Criteria:** Sensor out-of-range shall be detected. If a reference signal is present: reference mismatch shall be detected. Safe state within <200 ms.

**Rationale:** The DC link sensor provides the sum-current check against phase currents. Verifies graceful handling of its loss.

### C-08: IGBT Overtemperature (Simulated)

**Objective:** Verify FSR-08 - 1oo2 temperature voting and progressive derating.

**Covered:** SG-07 (ASIL B), FSR-08, H-07
**Status:** Executable - Defined | **Evidence:** -

**Procedure:**

1. Use a heat gun or programmable resistor to elevate one IGBT temp sensor reading above the warning threshold while the other remains normal.
2. Observe tractive effort derating via RTE.
3. Elevate the second sensor to the warning threshold. Verify further derating.
4. Elevate both above the critical threshold. Verify SSO entry.
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

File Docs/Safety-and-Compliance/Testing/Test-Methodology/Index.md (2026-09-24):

---
doctype: Test Plan
doc_id: OV-TEST-METHODOLOGY
title: Hardware Test Methodology — Standard Definitions and Methods
product_line: openvvvf
applies_to:
  - openvvvf-control-module
  - chassis-size-2
version: "0.1"
date: "2026-09-24"
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

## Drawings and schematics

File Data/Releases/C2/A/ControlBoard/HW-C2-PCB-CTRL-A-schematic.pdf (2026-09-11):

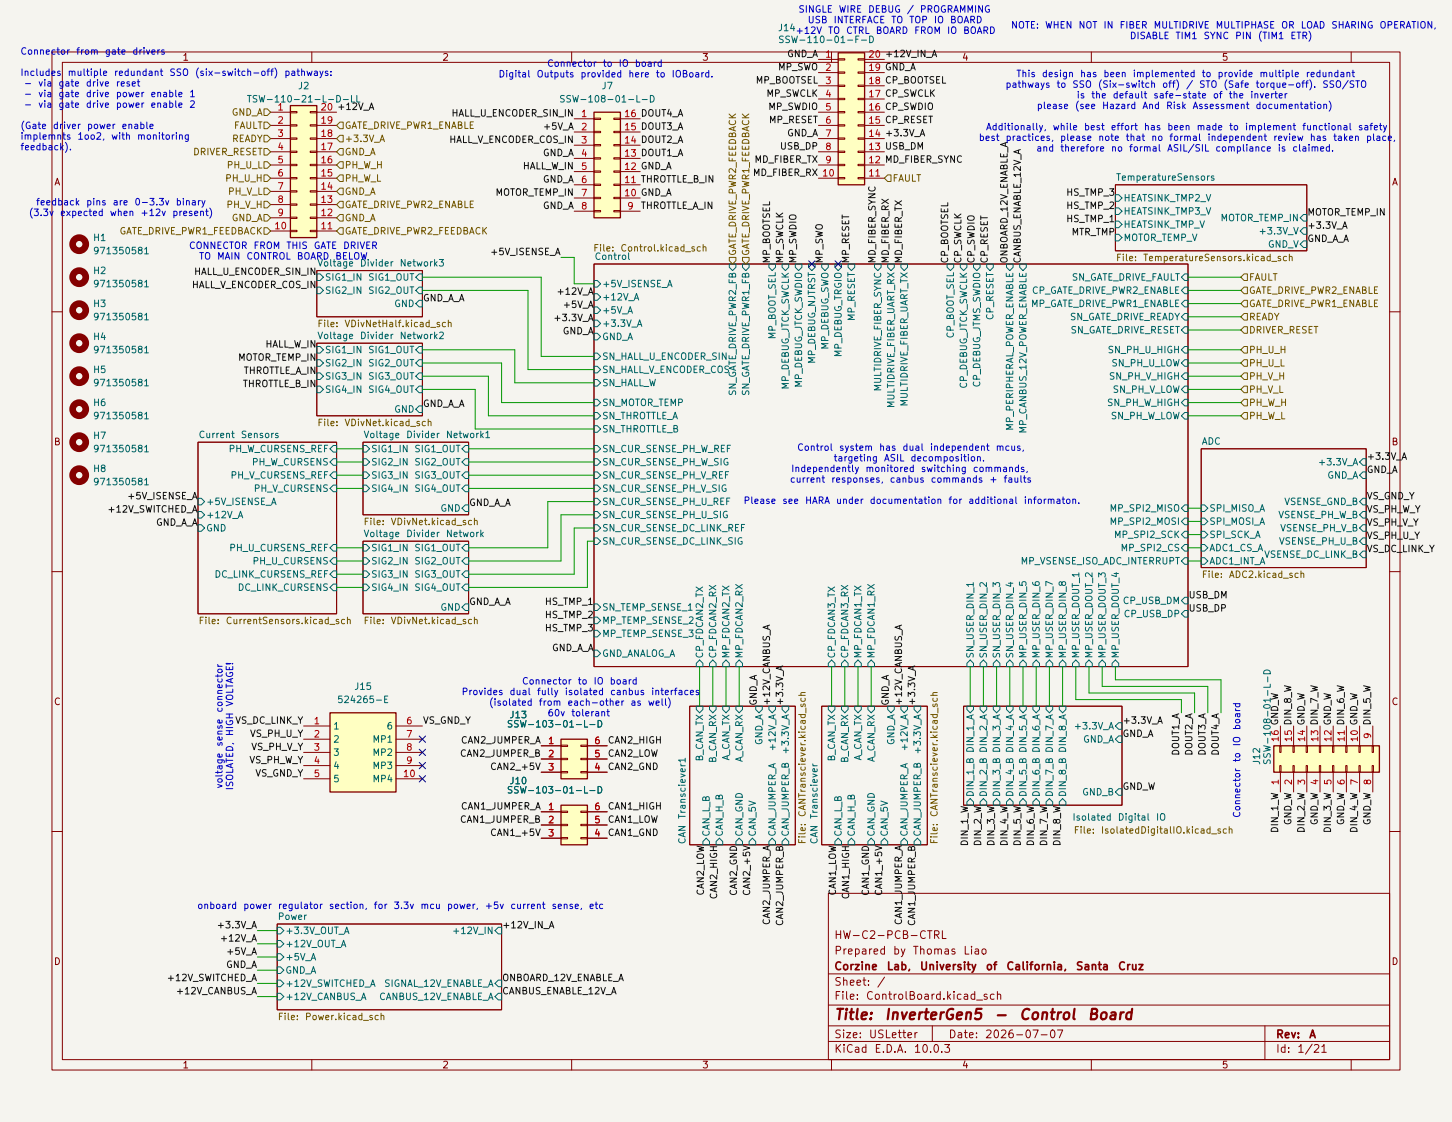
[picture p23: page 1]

Additionally, while best effort has been made to implement functional safety best practices, please note that no formal independent review has taken place, and therefore no formal ASIL/SIL compliance is claimed. NOTE: WHEN NOT IN FIBER MULTIDRIVE MULTIPHASE OR LOAD SHARING OPERATION, DISABLE TIM1 SYNC PIN (TIM1 ETR) Connector from gate drivers

Includes multiple redundant SSO (six-switch-off) pathways: - via gate drive reset - via gate drive power enable 1 - via gate drive power enable 2

This design has been implemented to provide multiple redundant pathways to SSO (Six-switch off) / STO (Safe torque-off). SSO/STO

is the default safe-state of the inverter please (see Hazard And Risk Assessment documentation)

(Gate driver power enable
implemnts 1oo2, with monitoring
feedback). feedback pins are 0-3.3v binary

TemperatureSensors File: TemperatureSensors.kicad_sch DC_LINK_CURSENS DC_LINK_CURSENS_REF GND

Independently monitored switching commands, current responses, canbus commands + faults Please see HARA under documentation for additional informaton. CONNECTOR FROM THIS GATE DRIVER
TO MAIN CONTROL BOARD BELOW
HALL_U_ENCODER_SIN_IN

PH_U_CURSENS PH_U_CURSENS_REF PH_V_CURSENS PH_V_CURSENS_REF PH_W_CURSENS PH_W_CURSENS_REF +12V_A +5V_ISENSE_A Current Sensors File: CurrentSensors.kicad_sch H2

onboard power regulator section, for 3.3v mcu power, +5v current sense, etc

Prepared by Thomas Liao
Corzine Lab, University of California, Santa Cruz
Sheet: /
File: ControlBoard.kicad_sch
Title: InverterGen5 - Control Board

Size: USLetter | Rev: A
KiCad E.D.A. 10.0.3 | Id: 1/21

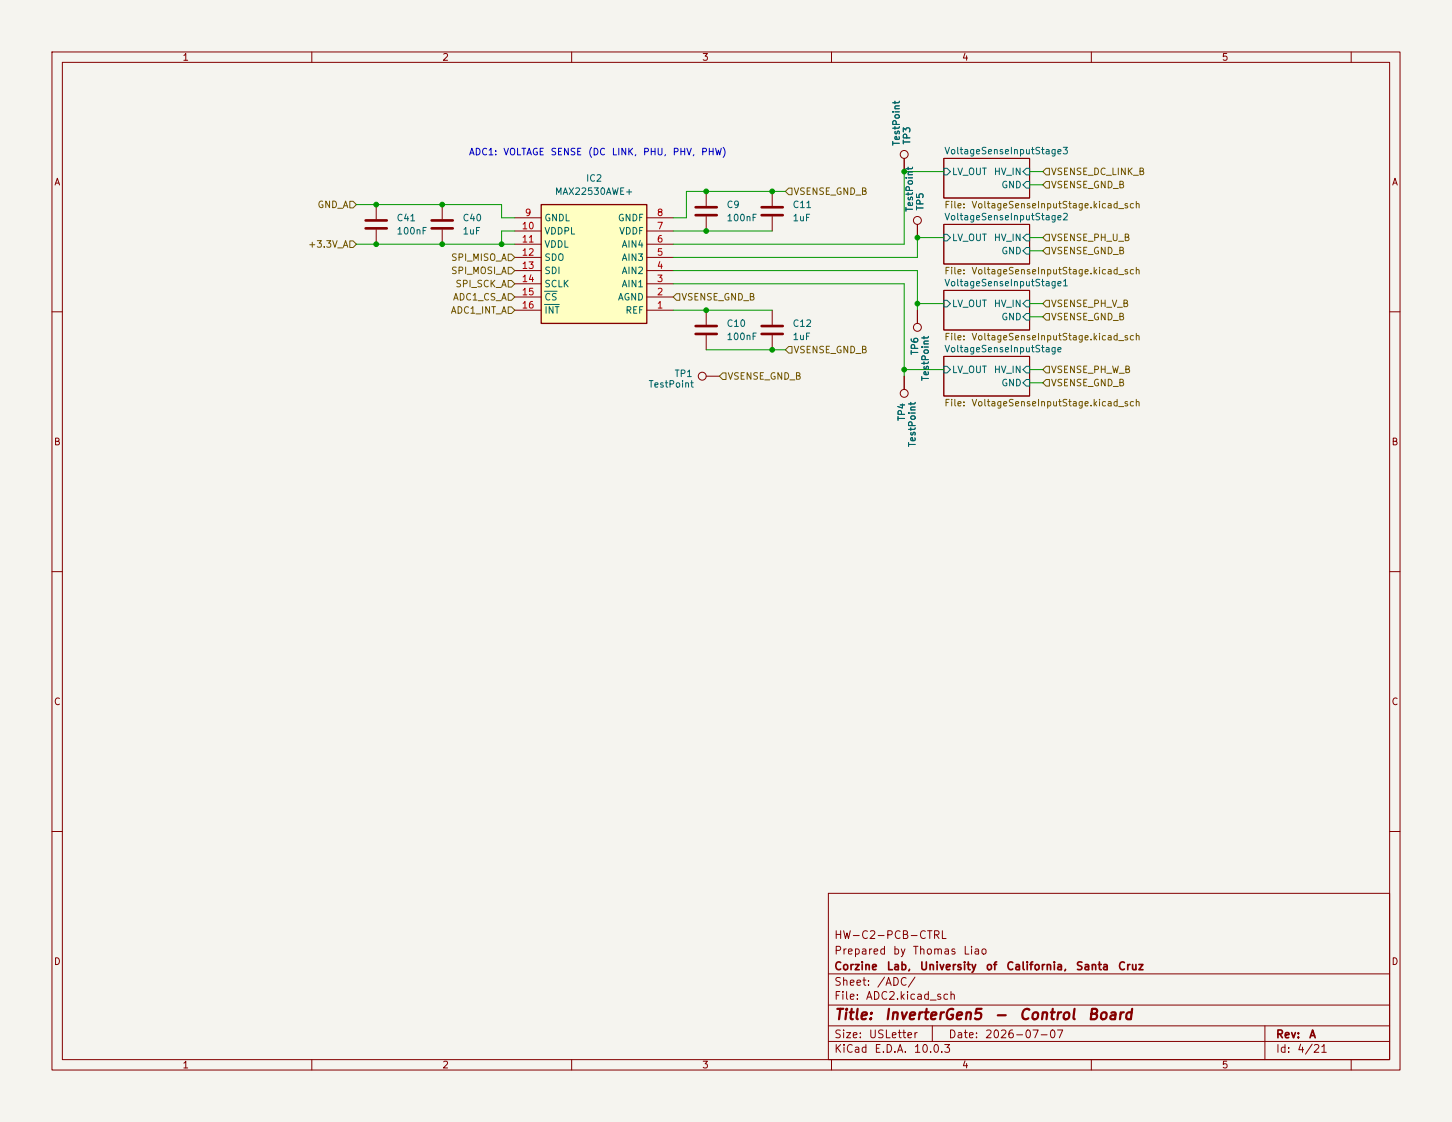
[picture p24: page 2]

HW-C2-PCB-CTRL
Prepared by Thomas Liao
Corzine Lab, University of California, Santa Cruz
Sheet: /ADC/
File: ADC2.kicad_sch
Title: InverterGen5 - Control Board

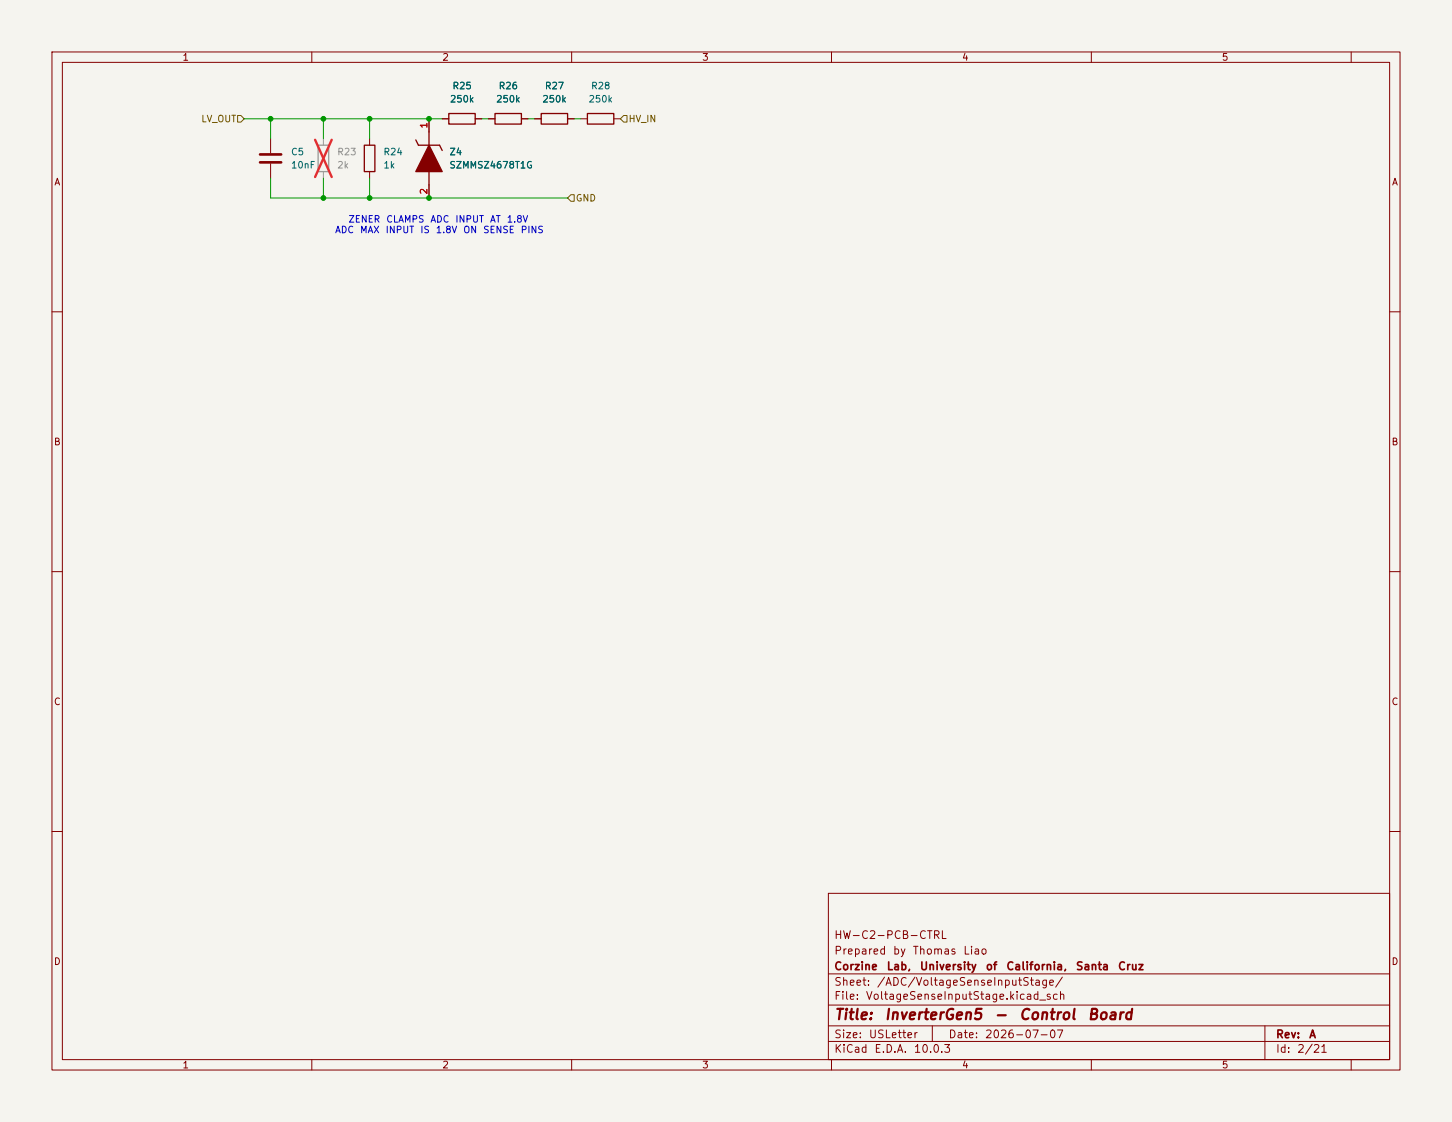
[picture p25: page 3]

ZENER CLAMPS ADC INPUT AT 1.8V
ADC MAX INPUT IS 1.8V ON SENSE PINS

HW-C2-PCB-CTRL
Prepared by Thomas Liao
Corzine Lab, University of California, Santa Cruz
Sheet: /ADC/VoltageSenseInputStage/
File: VoltageSenseInputStage.kicad_sch
Title: InverterGen5 - Control Board

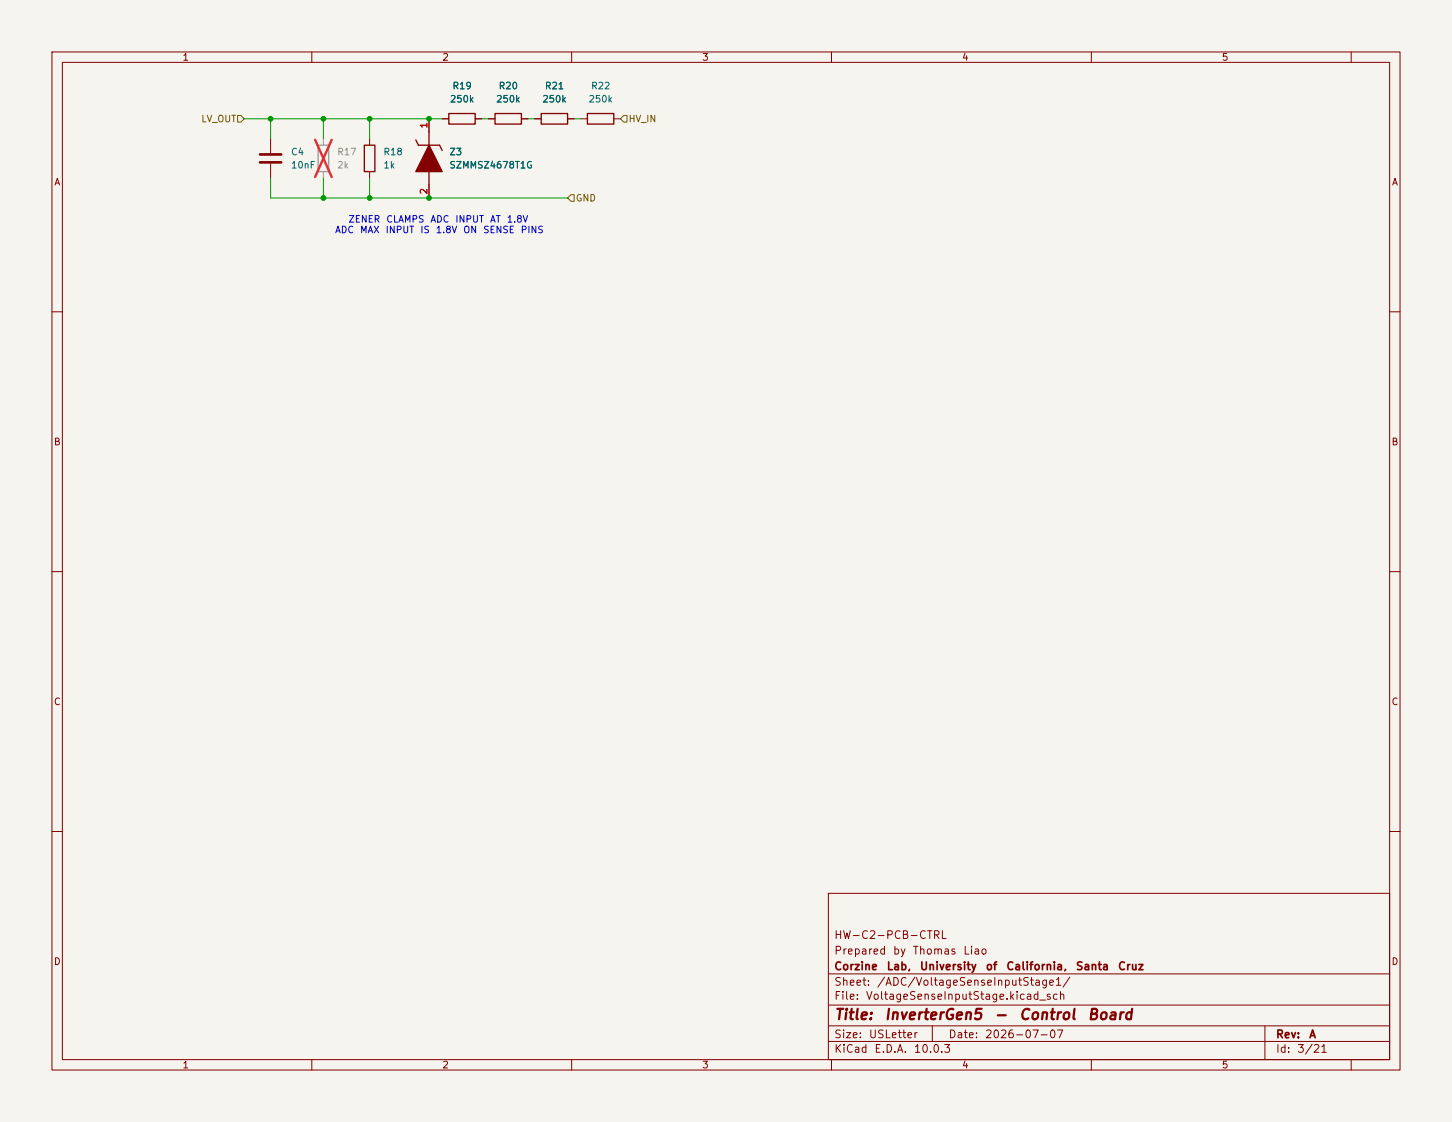
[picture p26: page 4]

ADC MAX INPUT IS 1.8V ON SENSE PINS R19

ZENER CLAMPS ADC INPUT AT 1.8V

HW-C2-PCB-CTRL
Prepared by Thomas Liao
Corzine Lab, University of California, Santa Cruz
Sheet: /ADC/VoltageSenseInputStage1/
File: VoltageSenseInputStage.kicad_sch
Title: InverterGen5 - Control Board

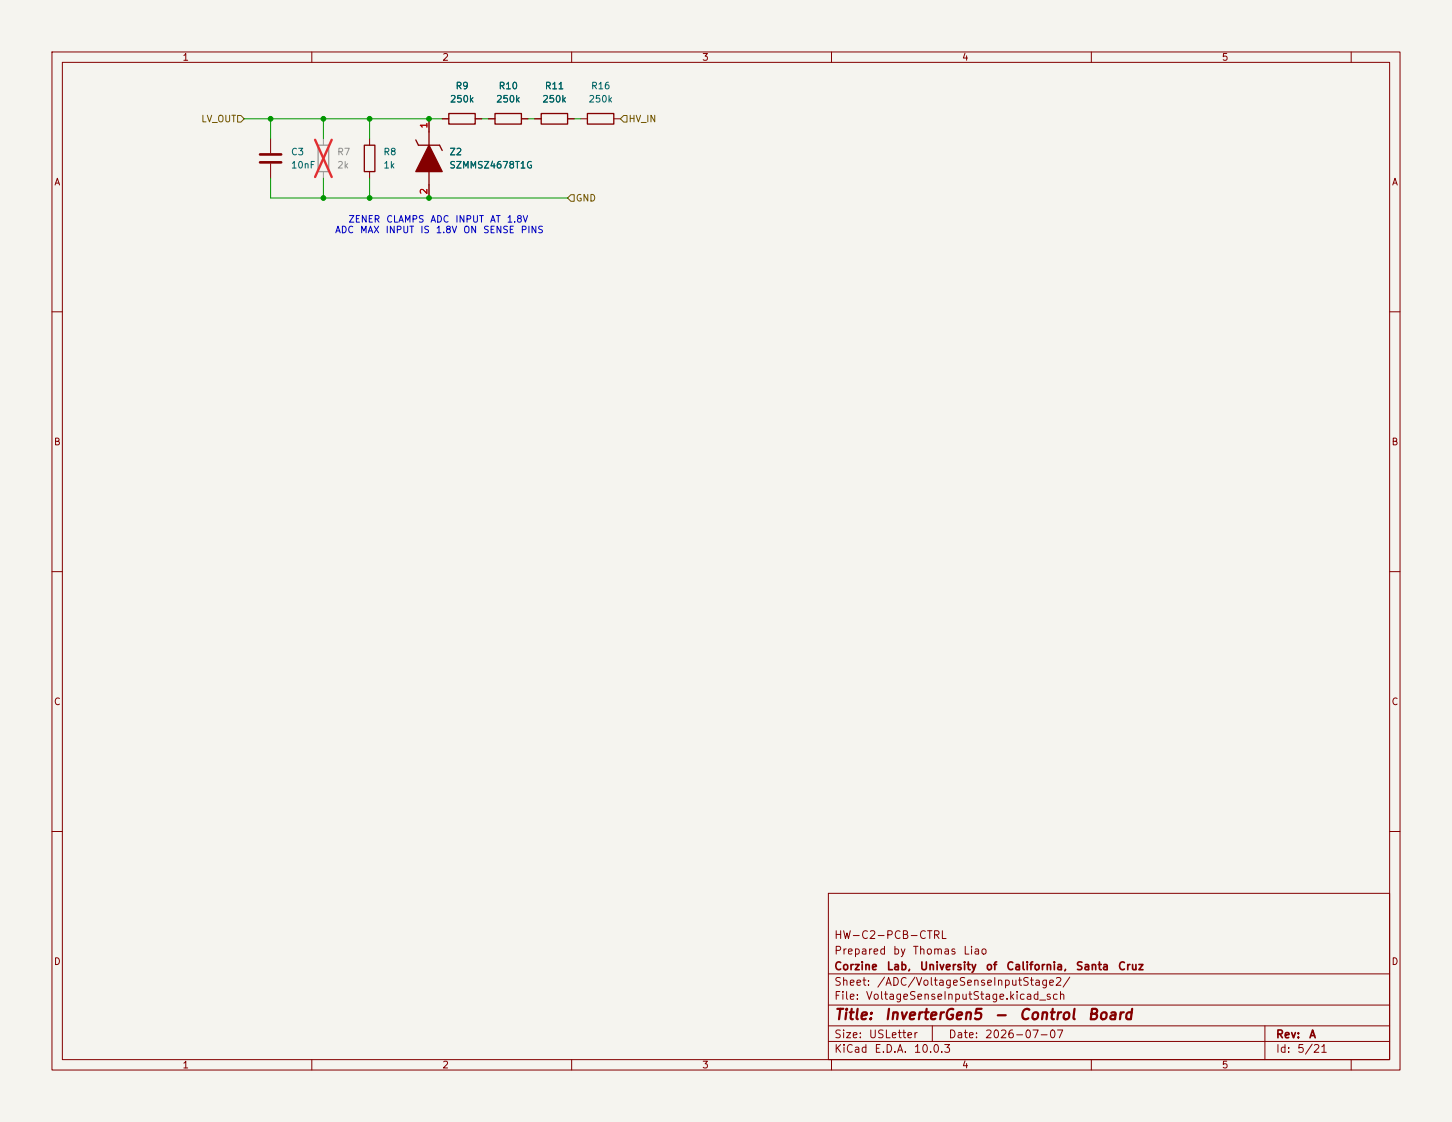
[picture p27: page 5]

ZENER CLAMPS ADC INPUT AT 1.8V
ADC MAX INPUT IS 1.8V ON SENSE PINS

HW-C2-PCB-CTRL
Prepared by Thomas Liao
Corzine Lab, University of California, Santa Cruz
Sheet: /ADC/VoltageSenseInputStage2/
File: VoltageSenseInputStage.kicad_sch
Title: InverterGen5 - Control Board

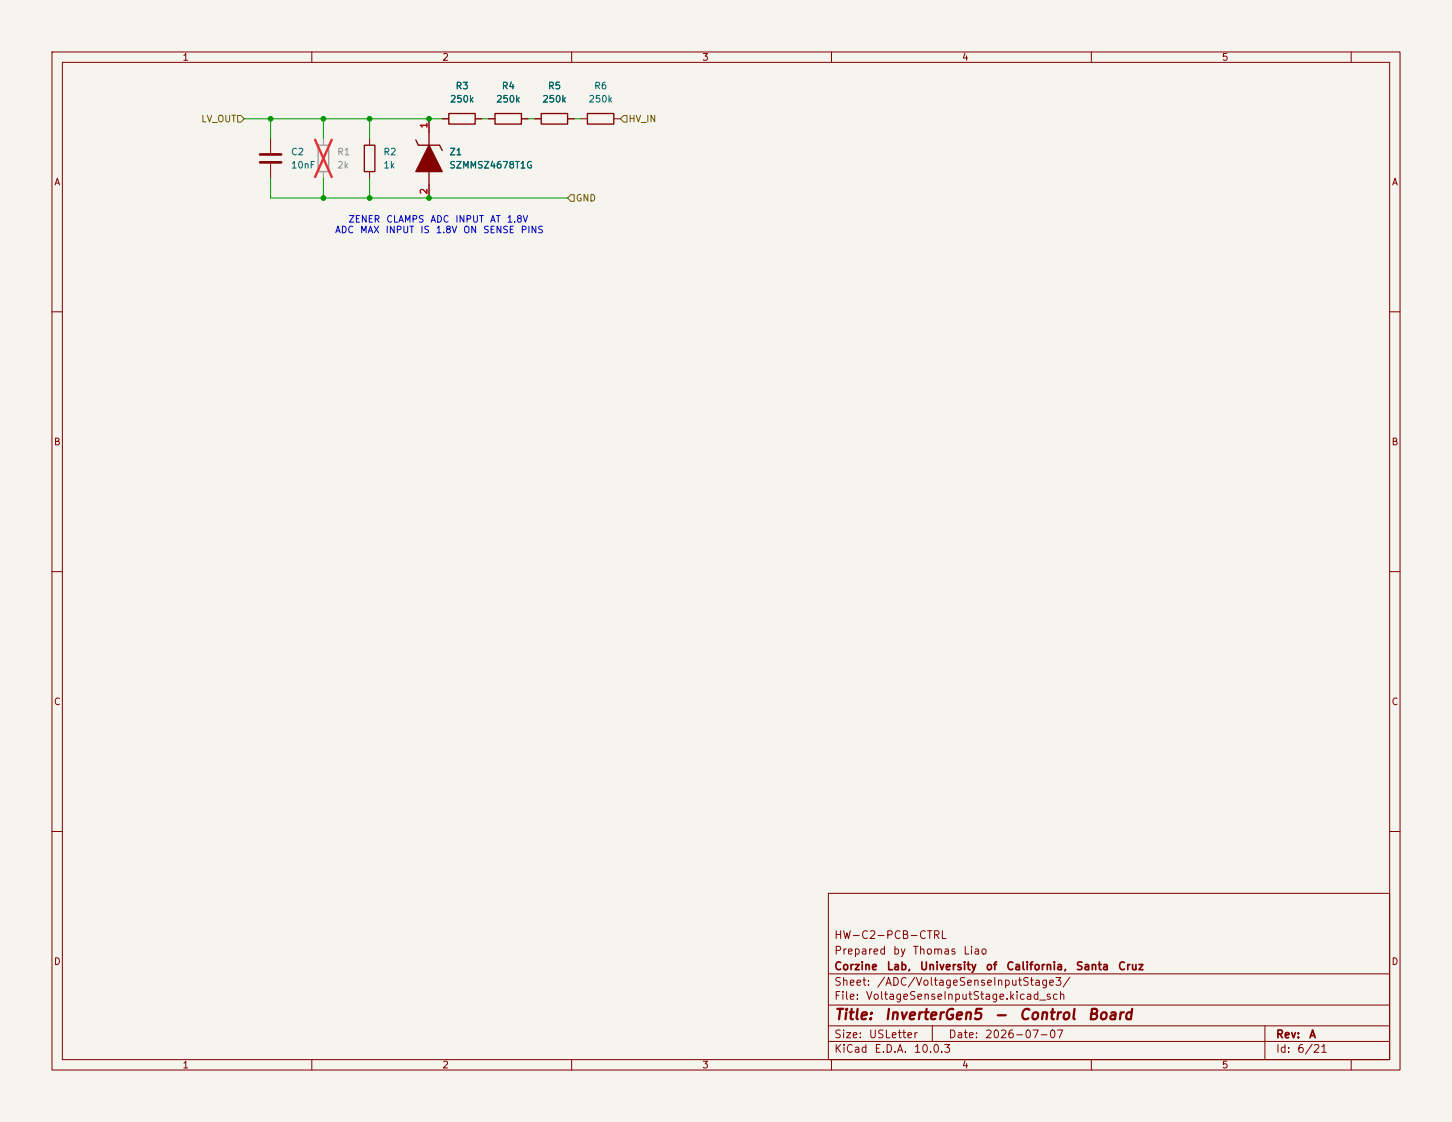
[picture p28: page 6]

ADC MAX INPUT IS 1.8V ON SENSE PINS R3

ZENER CLAMPS ADC INPUT AT 1.8V

HW-C2-PCB-CTRL
Prepared by Thomas Liao
Corzine Lab, University of California, Santa Cruz
Sheet: /ADC/VoltageSenseInputStage3/
File: VoltageSenseInputStage.kicad_sch
Title: InverterGen5 - Control Board

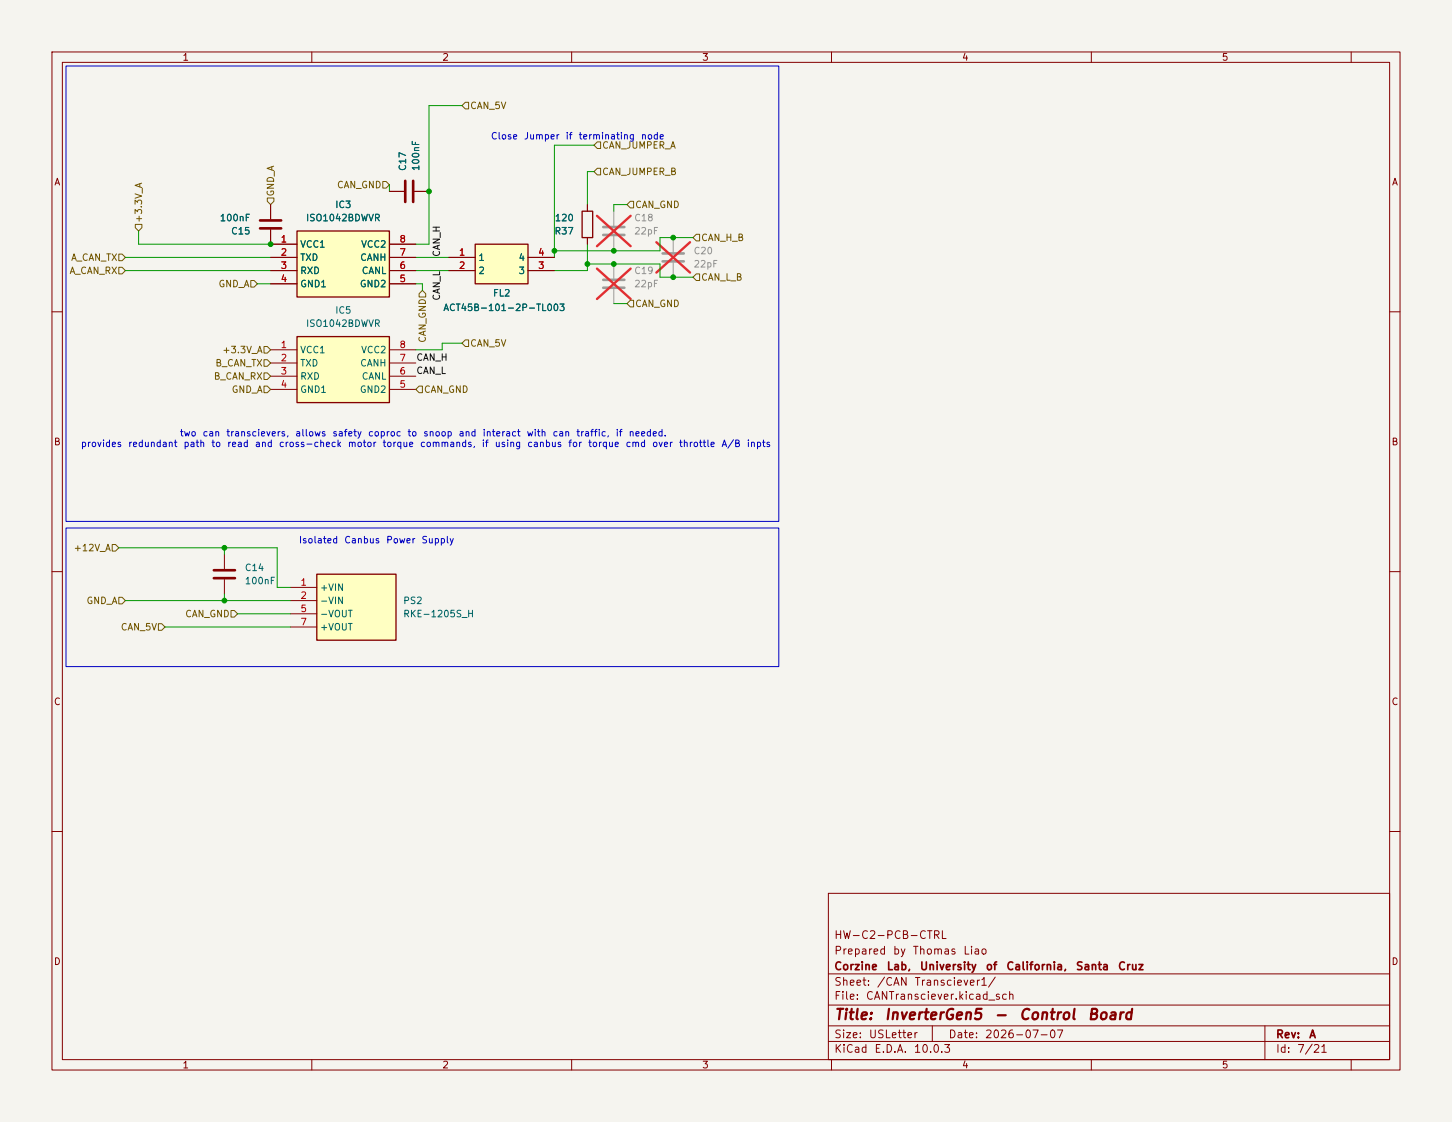
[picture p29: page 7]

two can transcievers, allows safety coproc to snoop and interact with can traffic, if needed. provides redundant path to read and cross-check motor torque commands, if using canbus for torque cmd over throttle A/B inpts Close Jumper if terminating node

HW-C2-PCB-CTRL
Prepared by Thomas Liao
Corzine Lab, University of California, Santa Cruz
Sheet: /CAN Transciever1/
File: CANTransciever.kicad_sch
Title: InverterGen5 - Control Board

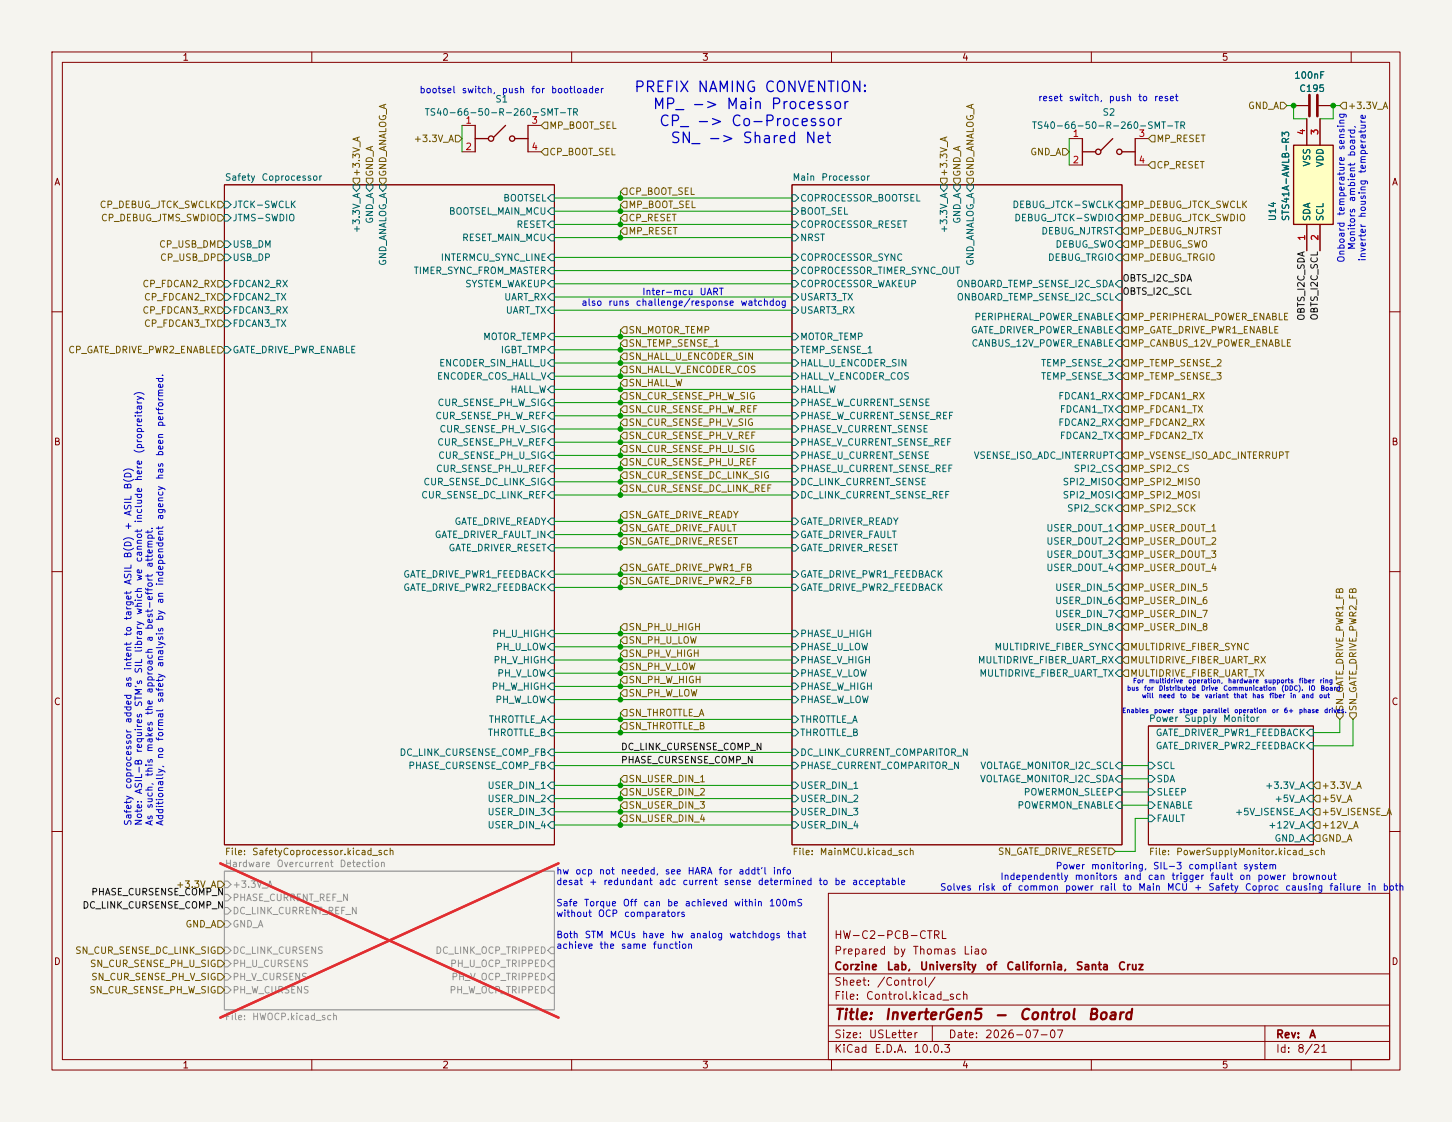
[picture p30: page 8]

bus for Distributed Drive Communication (DDC). IO Board will need to be variant that has fiber in and out Enables power stage parallel operation or 6+ phase drives. PREFIX NAMING CONVENTION:
MP_ -> Main Processor
CP_ -> Co-Processor

reset switch, push to reset

Inter-mcu UART also runs challenge/response watchdog

desat + redundant adc current sense determined to be acceptable Safe Torque Off can be achieved within 100mS without OCP comparators Both STM MCUs have hw analog watchdogs that achieve the same function Safety coprocessor added as intent to target ASIL B(D) + ASIL B(D) Note: ASIL-B requires STM's SIL library which we cannot include here (propreitary) As such, this makes the approach a best-effort attempt. Additionally, no formal safety analysis by an independent agency has been performed.

For multidrive operation, hardware supports fiber ring

Power Supply Monitor File: PowerSupplyMonitor.kicad_sch +3.3V_A DC_LINK_CURRENT_REF_N

hw ocp not needed, see HARA for addt'l info
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

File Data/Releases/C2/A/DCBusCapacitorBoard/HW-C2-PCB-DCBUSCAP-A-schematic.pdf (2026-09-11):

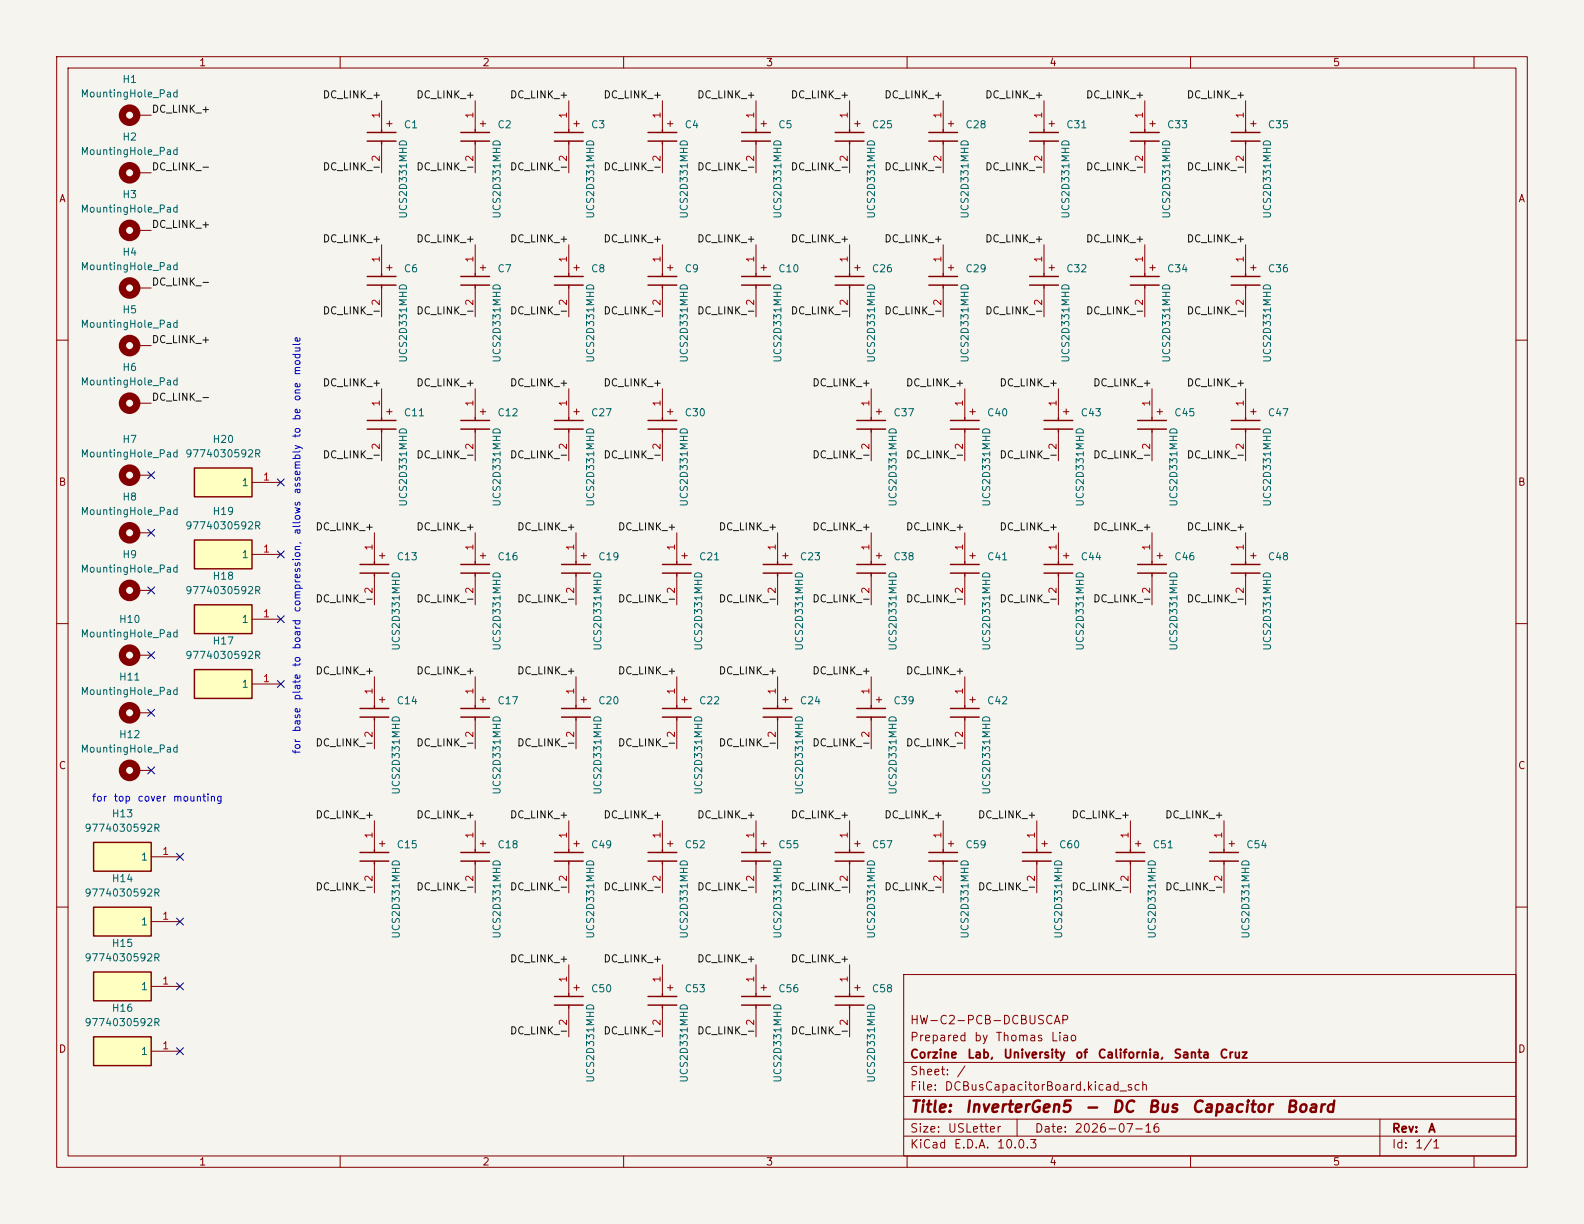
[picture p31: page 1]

DC_LINK_- for base plate to board compression, allows assembly to be one module

for top cover mounting

HW-C2-PCB-DCBUSCAP
Prepared by Thomas Liao
Corzine Lab, University of California, Santa Cruz
Sheet: /
File: DCBusCapacitorBoard.kicad_sch
Title: InverterGen5 - DC Bus Capacitor Board

Size: USLetter | Rev: A
KiCad E.D.A. 10.0.3 | Id: 1/1

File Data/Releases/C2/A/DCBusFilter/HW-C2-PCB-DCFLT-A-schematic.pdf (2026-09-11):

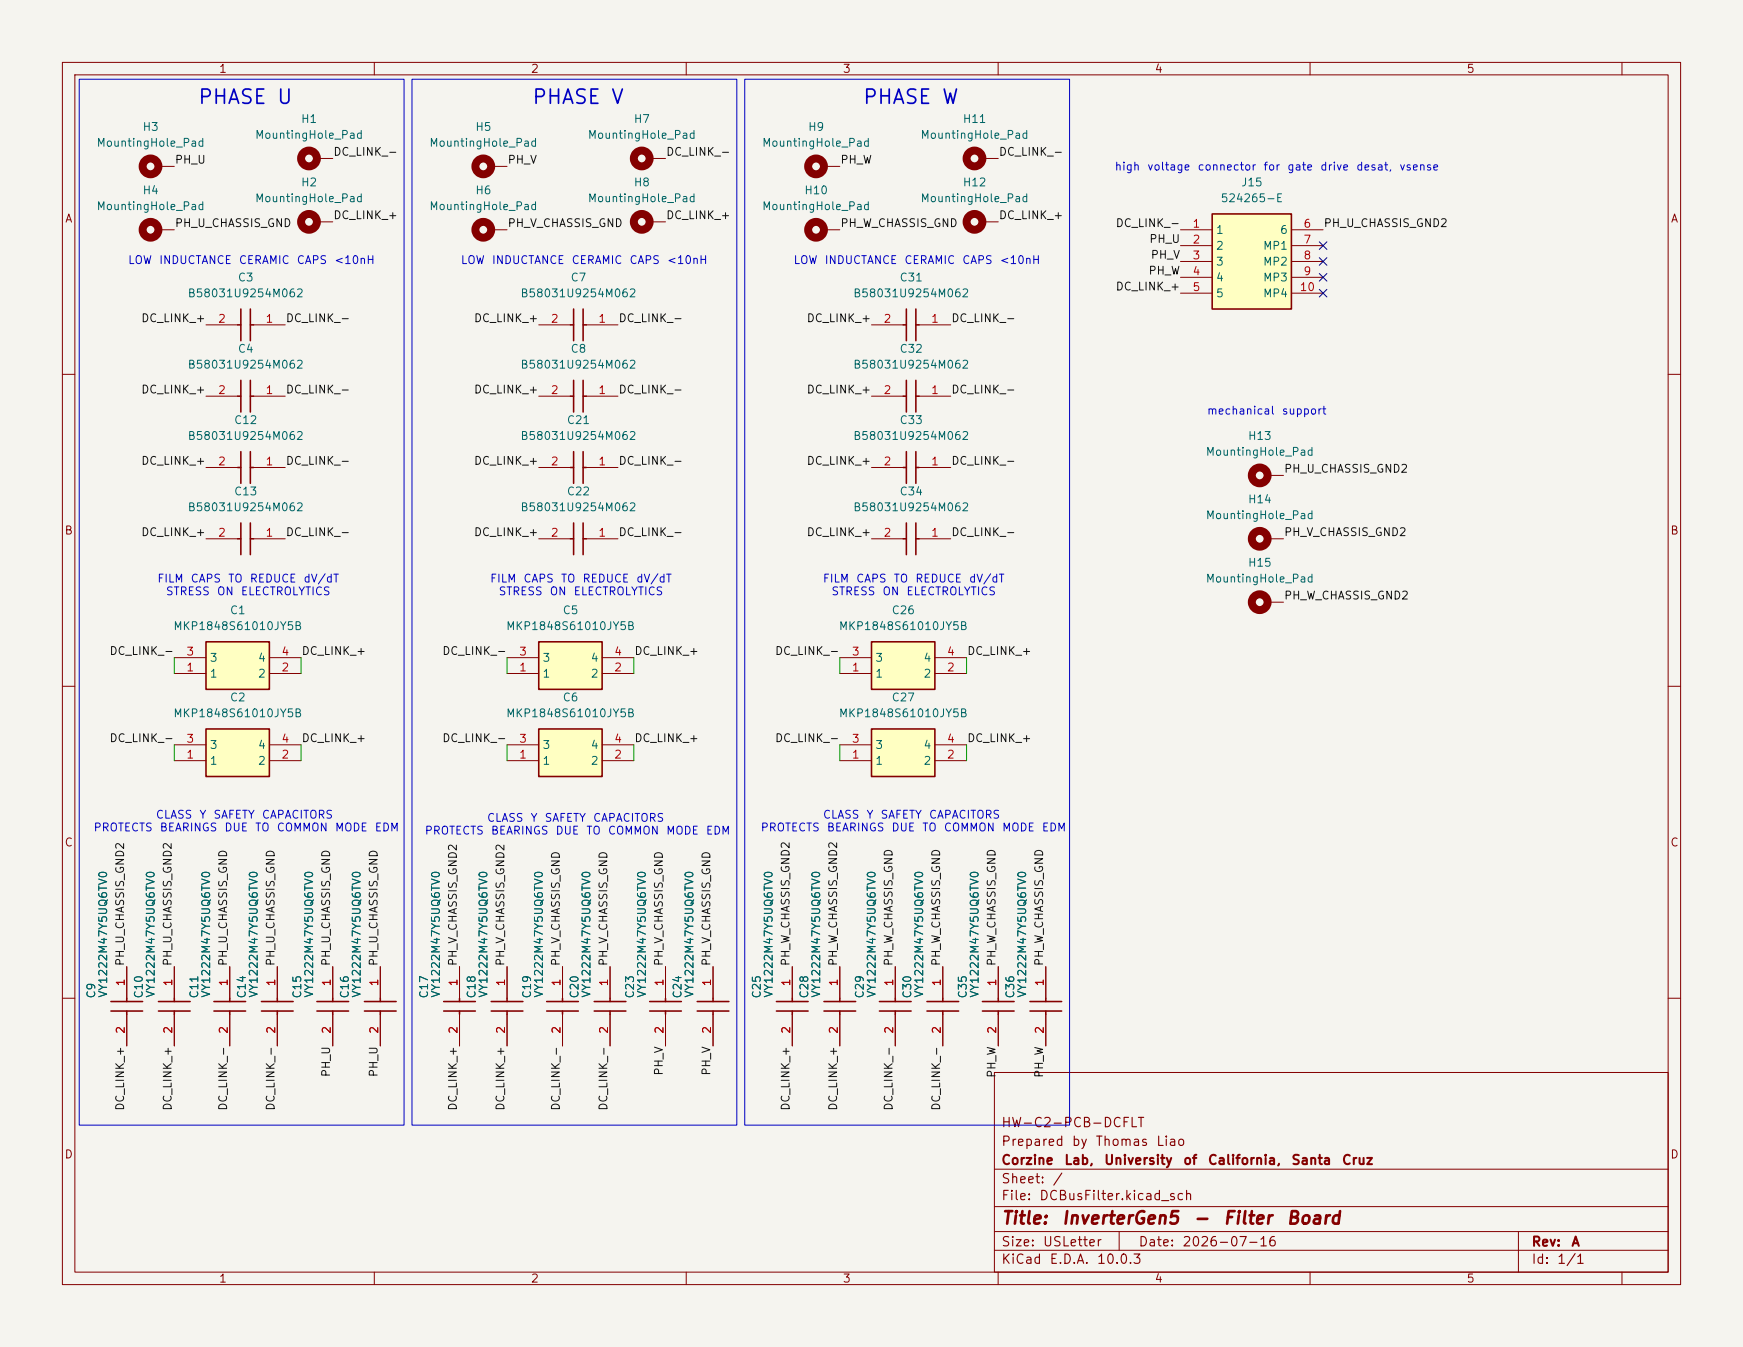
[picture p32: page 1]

CLASS Y SAFETY CAPACITORS PROTECTS BEARINGS DUE TO COMMON MODE EDM PHASE V

LOW INDUCTANCE CERAMIC CAPS <10nH PHASE U

FILM CAPS TO REDUCE dV/dT STRESS ON ELECTROLYTICS CLASS Y SAFETY CAPACITORS PROTECTS BEARINGS DUE TO COMMON MODE EDM

FILM CAPS TO REDUCE dV/dT STRESS ON ELECTROLYTICS

CLASS Y SAFETY CAPACITORS PROTECTS BEARINGS DUE TO COMMON MODE EDM

Prepared by Thomas Liao
Corzine Lab, University of California, Santa Cruz
Sheet: /
File: DCBusFilter.kicad_sch
Title: InverterGen5 - Filter Board

Size: USLetter | Rev: A
KiCad E.D.A. 10.0.3 | Id: 1/1

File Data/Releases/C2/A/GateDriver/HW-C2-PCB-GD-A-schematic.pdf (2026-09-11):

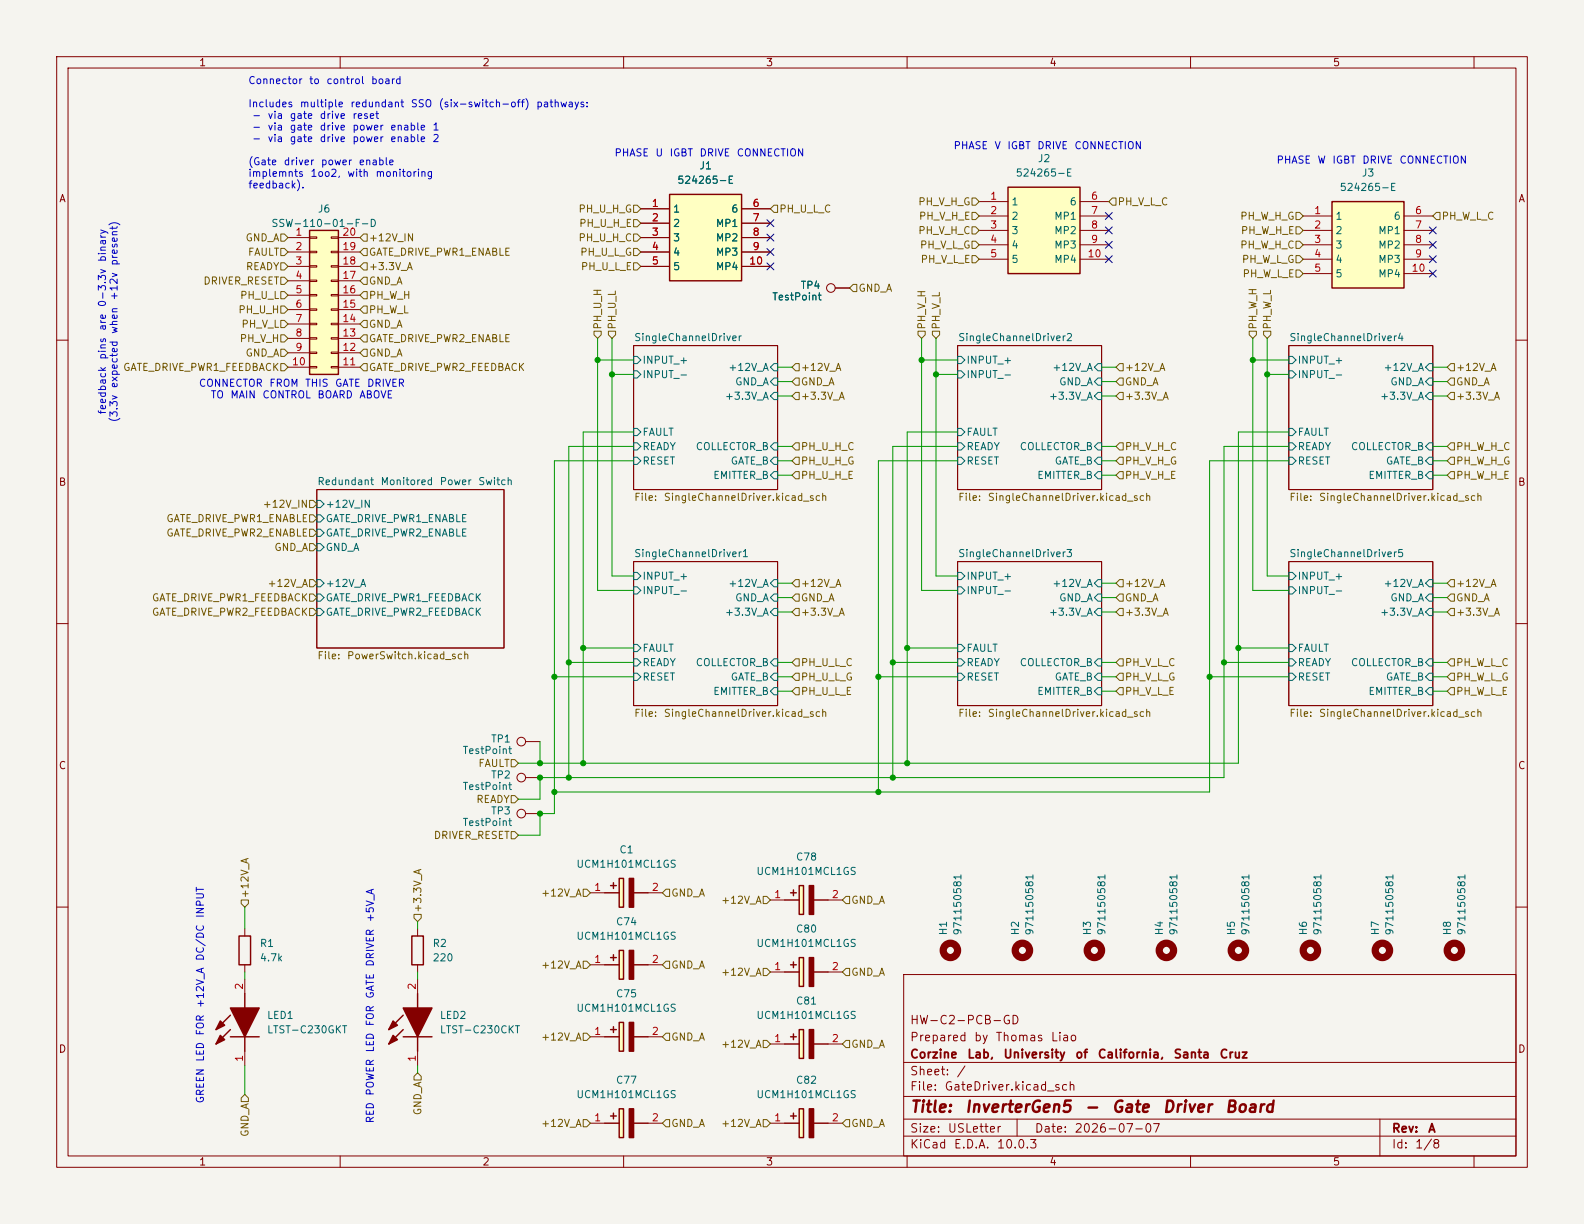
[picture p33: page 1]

Includes multiple redundant SSO (six-switch-off) pathways: - via gate drive reset - via gate drive power enable 1 - via gate drive power enable 2

(Gate driver power enable
implemnts 1oo2, with monitoring

PHASE W IGBT DRIVE CONNECTION

CONNECTOR FROM THIS GATE DRIVER

Prepared by Thomas Liao
Corzine Lab, University of California, Santa Cruz
Sheet: /
File: GateDriver.kicad_sch
Title: InverterGen5 - Gate Driver Board

Size: USLetter | Rev: A
KiCad E.D.A. 10.0.3 | Id: 1/8

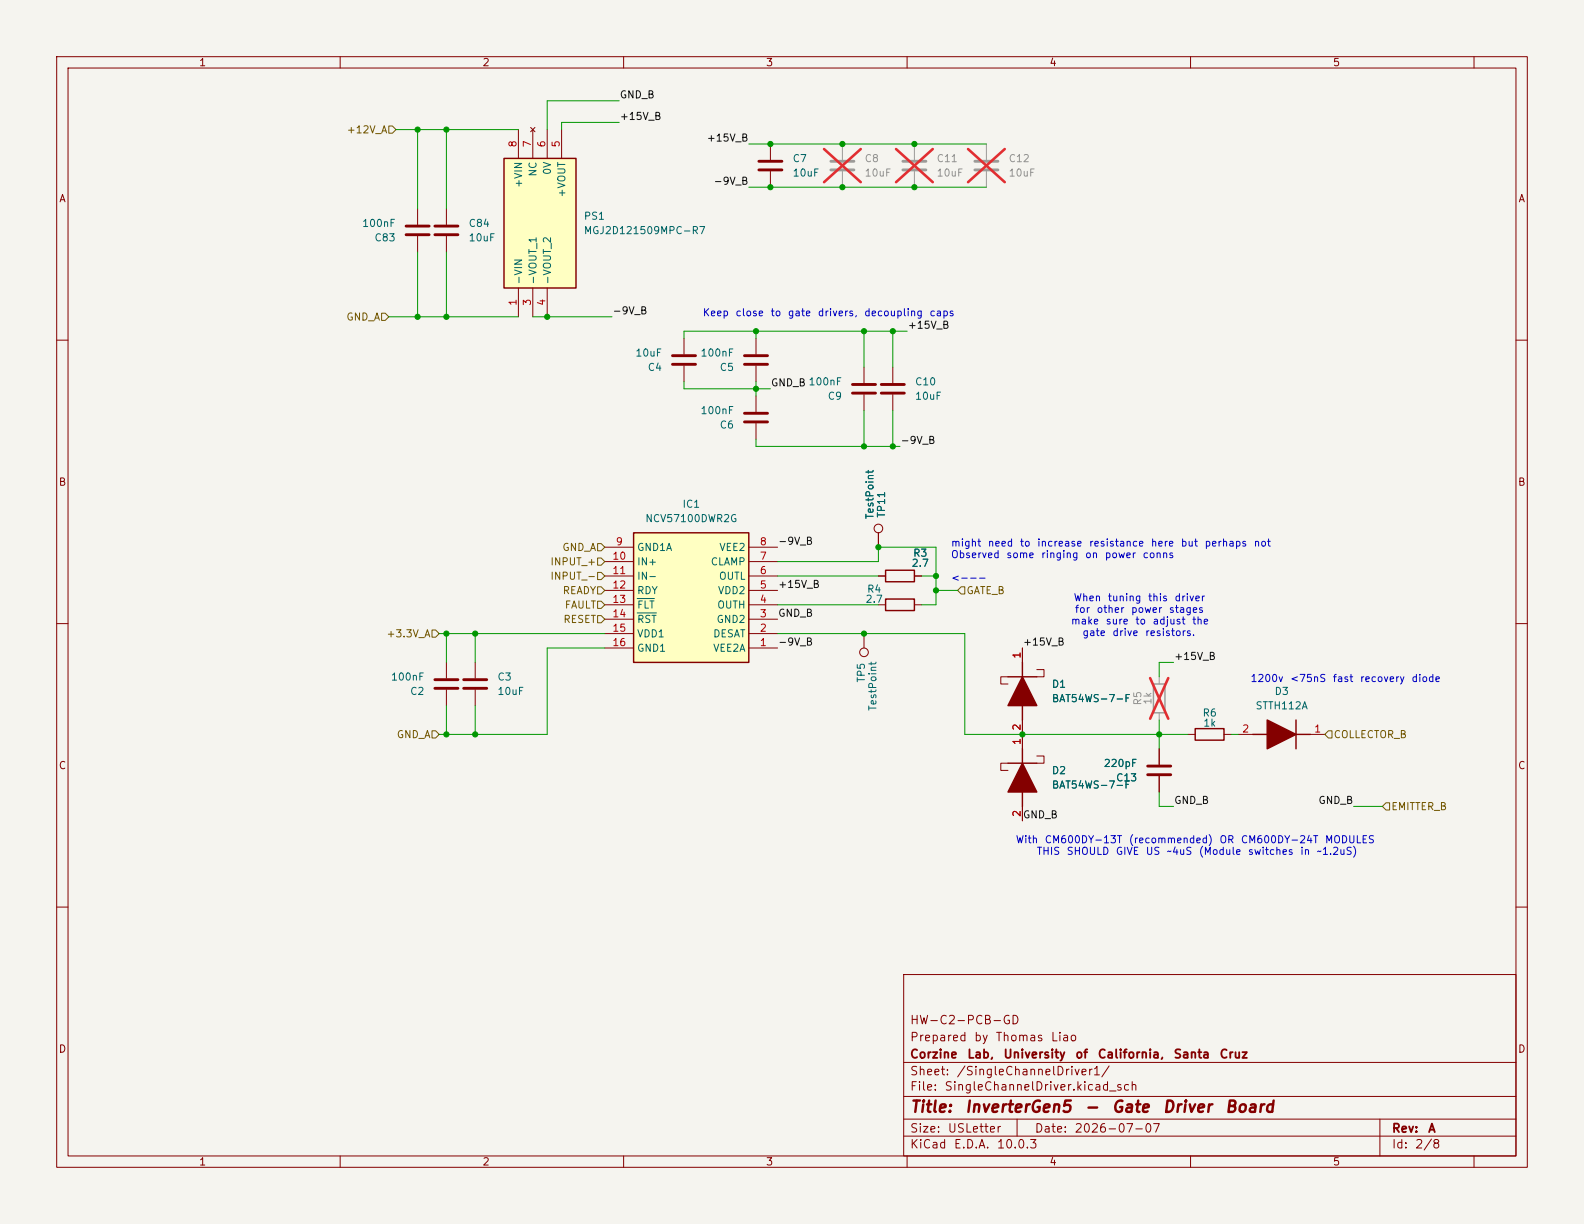
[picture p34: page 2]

GND_B When tuning this driver

With CM600DY-13T (recommended) OR CM600DY-24T MODULES

HW-C2-PCB-GD
Prepared by Thomas Liao
Corzine Lab, University of California, Santa Cruz
Sheet: /SingleChannelDriver1/
File: SingleChannelDriver.kicad_sch
Title: InverterGen5 - Gate Driver Board


THIS SHOULD GIVE US ~4uS (Module switches in ~1.2uS) D4BAT54WS-7-F 1 2 R7

GND_B When tuning this driver

With CM600DY-13T (recommended) OR CM600DY-24T MODULES

HW-C2-PCB-GD
Prepared by Thomas Liao
Corzine Lab, University of California, Santa Cruz
Sheet: /SingleChannelDriver2/
File: SingleChannelDriver.kicad_sch
Title: InverterGen5 - Gate Driver Board


GND_B When tuning this driver

With CM600DY-13T (recommended) OR CM600DY-24T MODULES

HW-C2-PCB-GD
Prepared by Thomas Liao
Corzine Lab, University of California, Santa Cruz
Sheet: /SingleChannelDriver/
File: SingleChannelDriver.kicad_sch
Title: InverterGen5 - Gate Driver Board


THIS SHOULD GIVE US ~4uS (Module switches in ~1.2uS) D10 BAT54WS-7-F 1 2 R15

GND_B When tuning this driver

With CM600DY-13T (recommended) OR CM600DY-24T MODULES

HW-C2-PCB-GD
Prepared by Thomas Liao
Corzine Lab, University of California, Santa Cruz
Sheet: /SingleChannelDriver3/
File: SingleChannelDriver.kicad_sch
Title: InverterGen5 - Gate Driver Board


GND_B When tuning this driver

With CM600DY-13T (recommended) OR CM600DY-24T MODULES

HW-C2-PCB-GD
Prepared by Thomas Liao
Corzine Lab, University of California, Santa Cruz
Sheet: /SingleChannelDriver4/
File: SingleChannelDriver.kicad_sch
Title: InverterGen5 - Gate Driver Board


THIS SHOULD GIVE US ~4uS (Module switches in ~1.2uS) D16 BAT54WS-7-F 1 2 R23

GND_B When tuning this driver

With CM600DY-13T (recommended) OR CM600DY-24T MODULES

HW-C2-PCB-GD
Prepared by Thomas Liao
Corzine Lab, University of California, Santa Cruz
Sheet: /SingleChannelDriver5/
File: SingleChannelDriver.kicad_sch
Title: InverterGen5 - Gate Driver Board


3.6v stm32 max voltage +12v to 3v voltage divider This circuit implements a redundent pathway for both mcus to implement Six Switch Open / Safe Torque Off in addition to regular pwm break and
gate driver reset. The following switches are independent systems with feedback monitoring. Each MCU cross monitors returned inputs, and can validate if the switch

Independent gate driver power switch, redundant 1oo2 SSO/STO

Prepared by Thomas Liao
Corzine Lab, University of California, Santa Cruz
Sheet: /Redundant Monitored Power Switch/
File: PowerSwitch.kicad_sch
Title: InverterGen5 - Gate Driver Board

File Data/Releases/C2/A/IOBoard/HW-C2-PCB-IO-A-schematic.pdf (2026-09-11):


BMS CAN1 +5V -> NOTE THIS IS NOT SEVCON PIN COMPATIBLE. DO NOT CONNEC THIS TO SEVCON

IT WILL BLOW UP

BMS CAN1 LOW ->
<- TRACTION BATTERY MINUS TERMINAL BMS CAN1 HIGH ->

<- MOTOR HALL V OR ENCODER COSINE (DEPENDING ON SENSOR TYPE) <- CONNECT TO DC LINK+, ALLOWS INVERTER TO PRECHARGE DC LINK

<- DASH, CHARGER, ABS CANBUS LOW

<- MOTOR THERMISTOR (TIE OTHER END OF THERMISTOR TO GND_A) NOTE TO USER: THEY MUST CONNECT EXTERNAL PRECHARGE RESISTOR

Connector to IO board SINGLE WIRE DEBUG / PROGRAMMING USB INTERFACE TO TOP IO BOARD +12V TO CTRL BOARD FROM IO BOARD

CONNECT SWITCH BETWEEN +12V_A AND THIS PIN ->

BLANK TO ISOLATE TRACTION BATTERY VOLTAGE ->

traction power is not applied when trpwr is on, offboard main power system should power loads instead. <- OUTPUT, TIE TO SEVCON DC/DC ENABLE PIN

USER DIGITAL INPUT 1 (see ctrl board for v/current limits) ->

AUX 12V OUT, TO DISPLAY, KEYSWITCH ->

THROTTLE HOME POSITION SWITCH (REF'D TO THROTTLE +5V) ->

enables/disables aux 12v output.

(FOR FIBER IO MULTIDRIVE MODULE, ETC) ALLOWS MULTI-DRIVE MANY PHASE (>3) OR LOAD SHARING

Note, when system is running, this output must not be on due to power constraints with onboard regulator

intended use case is to run aux systems while

HW-C2-PCB-IO
Prepared by Thomas Liao
Corzine Lab, University of California, Santa Cruz
Sheet: /
File: IOBoard.kicad_sch
Title: InverterGen5 - IO Board

SEVCON DC/DC ENABLE CIRCUIT

Size: USLetter | Rev: A
KiCad E.D.A. 10.0.3 | Id: 1/1

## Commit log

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2026-08-07 Phase 1-2: clean build artifacts, normalize doc metadata, nested navigation
    - Remove committed/ignored build artifacts (*.egg-info, __pycache__, .pytest_cache)
    - Move generated product manual to build/manuals/
    - Rename section README.md files to Index.md
    - Add description and nav_order to all Docs/ frontmatter
    - Rewrite Docs/Index.md as a card-based portal
    - Update site.py for nested sidebar, nav_order sorting, and descriptions
    - Fix breadcrumbs to use docs-relative paths
    - Add make site target and tighten check-clean
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2026-08-07 Phase 4: modern ABB-inspired manual template, remove prepared frontmatter field
    - Rewrite page.html with light header, print button, cleaner nav
    - Rewrite style.css with light industrial palette, red accent, refined sidebar,
    chapter-number boxes, styled callouts, clean tables/figures
    - Add print.css for print-friendly output
    - Update site.py to skip empty/prepared frontmatter fields, inject chapter
    data attributes, and apply DANGER/WARNING/NOTE/TIP callout classes
    - Remove prepared: field from all Docs/**/Index.md files
2026-08-07 fix: collapse document frontmatter into compact metadata panel
    - Show only doc_id, version, status, date in a one-line summary
    - Hide the full frontmatter table behind a <details> disclosure
    - Keep full table visible when printing
2026-08-08 docs: cleanup pass — design docs, schema, badges, testing scaffold
    - Move C2 thermal analyses from User-Manual and Assembly-Guide into new
    Docs/Power-Stages/C2/Design-Documents/ with consistent OV-C2-DD-* doc_ids
    - Unify top-level nav order and rename top-nav 'Safety' → 'Safety and Compliance'
    - Fix breadcrumbs to use document titles instead of directory display names
    - Add 'Getting Started' audience card to landing page
    - Document frontmatter schema, doc_id prefixes, and nav_order conventions in
    Docs/Agents.md
    - Add frontmatter schema validation (required fields, enums, nav_order
    uniqueness, doc_id prefix warnings)
    - Add document templates (Index, assembly step, test report, desig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
2026-08-08 Phase 2: fix C2 User Manual images and HARA v5.7 consistency
    - Copy missing board-render PNGs from InverterGen5/Hardware/Chassis2/Boards/
    into Docs/Power-Stages/C2/User-Manual/ and fix relative image paths
    - Update companion-document block and inline SWAD references to use current
    doc_ids (OV-CA-SWM-INDEX, OV-SW-MAINMCU-INDEX)
    - Replace old Docs/DC_LINK_THERMAL_ANALYSIS.md reference with OV-C2-DD-DCLINK-THERMAL
    - Align thermal-management description with HARA Core v5.7:
    - 2 IGBT NTC sensors + 1 DC link capacitor NTC (was 3 IGBT NTCs)
    - 1oo2 voting for IGBT temperature (was 2oo3)
    - Immediate SSO at critical threshold (was ramp-to-zero)
    - Align CAN heartbeat timeout actions with imme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
2026-08-08 docs: clean up titles, remove em dashes, fix assembly-guide numbering
    - Remove redundant parent-section prefixes from document titles and H1s.
    - Replace all em dashes with hyphens across Docs and templates.
    - Wire assembly-guide CSS class so folder-derived chapter/step numbers are used
    and CSS auto-numbering is suppressed for assembly-guide pages.
    - Restore manual section numbers in C2 assembly-guide chapters/steps.
    - Clarify system thermal analysis title to mention inverter efficiency and
    heatsink/baseplate sizing.
2026-08-08 docs: shorten thermal analysis title and add sponsors section
    - Rename system thermal analysis to just 'System Thermal Analysis'.
    - Add sponsors section to the docs landing page (Docs/Index.md) and README.
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2026-08-08 docs: split resistance and inductance LCR references; fix site links
    - Move Ls-Rs inductance measurements and images into Inductance.md.
    - Keep only DCR resistance data in Resistance.md.
    - Update index links to use .html so they work on the generated site.
    - Remove placeholder flag from Inductance.md now that it has reference content.
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2026-08-09 Make PMSM and induction calibration subcategories menu-only, fix Testbed frontmatter, expand test dashboard
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2026-08-09 Add induction motor inductance calibration results
    - Add induction-inductance-cal.jsonl and plot.
    - Replace placeholder Inductance.md with test report.
    - Include 40/80/120 V bus sweep data and comparison to LCR reference.
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2026-08-09 Fix PDF path generation for mixed-case source filenames
    Use url_path from the site generator so HTML filenames match exactly,
    especially on case-sensitive filesystems.
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2026-08-13 Reorganize docs: drop status/reviewed fields, split HARA, restructure Testing and assembly guide
    Schema/tooling:
    - Remove status and reviewed frontmatter fields everywhere; maturity is
    now conveyed by version + the placeholder flag, which alone drives WIP
    badges in nav, cards, and banners
    - Add "Test Plan" doctype; docgen rewrites relative .md links to built
    .html URLs so source-path links work on GitHub and in the site
    - Fix Docs/Agents.md drift: four top-level sections incl. Tools,
    OV-TOOLS-* prefix, 600-699 nav range, Tool Manual doctype
    HARA Core (2380 -> 566 lines):
    - Extract the full fault-injection test plan (C/S/I series) to
    Testing/Firmware/Fault-Injection-Test-Plan (OV-T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
2026-08-13 Re-file fault-injection plan under Testing/, apply committee review fixes
    - Move Fault-Injection-Test-Plan from Testing/Firmware/ to Testing/
    (doc_id OV-TEST-FW-FAULT-INJECTION -> OV-TEST-FAULT-INJECTION): its
    C/S/I/E series span control module, power stage, and system levels;
    preamble now documents the filing rule and the plan-vs-evidence
    pattern (dated Test Reports reference the plan by test ID)
    - Testing/Index.md: new Safety-mechanism validation dashboard section,
    "file by DUT, not bench equipment" domain rule; drop phantom
    chassis-size-3 from applies_to (no C3 evidence exists)
    - Testing/Firmware/ reverts to an empty menu_only placeholder
    - HARA Core: fix dangling Section 10 /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
2026-08-13 Add OpenVVVF branding: logo, favicons, Saira font, global footer, branded PDF covers
    - Vendor deterministic brand generators (Tools/DocGen/brand/) and
    generated assets (wordmark SVG/PNG, icon set, Saira OFL fonts) under
    templates/brand/, copied to site/brand/ on build
    - Site header shows the wordmark; favicon/apple-touch icons added;
    headings use Saira; accent color updated to brand red #FC0F27
    - New global footer on every page: brand block, Documentation/Project
    link columns, sponsor logos (moved off the landing page), legal line
    - Fix: the fixed sidebar was covering the footer's left column on
    desktop; footer now offsets by sidebar width and collapses with it
    - Print covers resty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
2026-08-15 docgen: improve PDF cover page layout
    - Add top/bottom red accent bars and a cleaner cover-page structure.
    - Include a sponsors section on the cover page.
    - Keep page footer as plain 'OpenVVVF Documentation' text (per-page logo
    experiment reverted).
    - Add black-and-white logo assets for future print use.
2026-08-15 docgen: stamp running headers, tighten cover, caption figures
    - Running header (doc title/id + rule) is now stamped onto the PDF like
    the footer, sitting higher with clearance above the content
    - Cover title moved up under the header divider; description shown as
    a red-bar note box
    - Standalone images become centered figures with captions from alt
    text, capped at 10cm so two fit per page
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2026-08-15 Draft C2 assembly prerequisites chapter skeleton
    Replaces the Preparation placeholder with a structured skeleton:
    prerequisites (control assembly completed and tested, firmware
    flashed), required documents, tools, consumables, workspace/ESD, and
    safety. Marked placeholder pending real part numbers and torque values.
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2026-08-15 Fix print info page leaking onto web view; link C2 sub-guides
    .print-info is now hidden on screen like .print-cover, and the C2
    index bullets for the integration guide, assembly guide, and design
    documents are actual links.
2026-08-16 Fix advertised C2 DC-link voltage range to 150/200/400 V class
    The advertised range depends on the DC-link capacitor fitted; 140 V
    was the nominal bus of the tested unit and remains in the test and
    thermal documents that describe that specific hardware.
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2026-08-16 Remove Docs/Software section until the software docs are ready
    Firmware, RTE Studio, and encoder-calibration documents were all
    placeholder or not-ready material; the section is removed and will be
    re-added after the rewrite. The landing page drops the Software card
    and nav link, the site header/footer nav loses the Software entry, and
    the control-assembly Software Manual no longer references the removed
    documents.
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2026-08-16 docgen: improve mobile and narrow-viewport layout
    - Add a 1100px breakpoint that shrinks the sidebar to 260px and reduces
    nested indentation so narrow desktops/tablets don't feel crushed.
    - At <=900px: smaller header, hide the / Documentation wordmark, shrink
    logo, hide the Print button label, and scale down heading sizes.
    - Make wide tables horizontally scrollable on small screens instead of
    wrapping columns awkwardly.
    - Reduce blockquote/callout padding and frontmatter font size on mobile.
    - Keep the mobile drawer usable with tighter nested nav spacing.
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2026-08-16 BOM Tool: live BOM regeneration at export, price estimates, home-linked logo
    - hwrelease update now runs the repo's BOMManager generate (--variants,
    cached prices) against the exported tag tree, so vendor BOMs are rebuilt
    from the tag's KiCad sources instead of copied (never stale); falls back
    to committed BOMs with a warning if generation is unavailable.
    - Pricing_Report.md is exported and parsed; the BOM Tool shows per-vendor
    subtotals on the buttons and the grand total estimate in the header.
    - Logo on PCB Tool / BOM Tool links back to the documentation home page.
    - Installed bom-manager + requirements into the venv (also fixes the
    pre-existing BOMManager test failure: 60 passed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
    [Consolidated_BOM.csv, assembly_bom.csv, mcmaster_bom.csv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]
2026-08-16 Fix sparse vendor BOMs: export board BOM CSVs before generate
    BOMManager discovers board BOMs as <Board>.csv beside the KiCad project,
    which don't exist in a raw git archive — so the first live generate saw
    only 7 non-board sources (21 lines, Mouser undercounted). The update now
    exports each board's BOM CSV from its schematic into the temp tree before
    generating: 12 sources, 90 lines, Mouser 612.97, est. total 198.58.
    [Consolidated_BOM.csv, mouser_bom.csv, pcb_bom.csv]
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2026-08-17 BOM Tool: PCB-Tool-style UI rework; GP1500 price
    - Left sidebar (surface bg) with chassis/revision/variant selectors and a
    vendor list showing prices as subtext; main area keeps order links,
    preview, and a wider 560px walkthrough column.
    - Bergquist GP1500 thermal pad manual price 32.78 USD (qty breaks noted).
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2026-08-17 Qty on mech cards; purge stale vendor CSVs from variants; tempdir fix
    - Spec cards show quantities; tap/countersink specs and updated SendCutSend
    prices are live (subtotal 416.42 USD, est. total 2391.64 USD).
    - BOMManager: write_variant_outputs now removes stale vendor CSVs from
    variant dirs (kills the lingering digikey_bom.csv in standard/generous).
    - hwrelease temp extraction moved to repo root (.hwrelease-tmp-*, gitignored)
    so a killed run can't break the docgen site build.
    [Consolidated_BOM.csv, HW-C2-PCB-CTRL-A.step, HW-C2-PCB-DCBUSCAP-A.step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]
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2026-08-17 Fabricated-part qty harvest from the model; BSP label fixed upstream
    model_parts.json instance counts are cross-checked against info.txt
    quantities (currently zero mismatches). Base plate extracts as HW-C2-BSP-A.
    [HW-C2-BSP-A.step, HW-C2-CHSP-A.step, HW-C2-DCLBB-A.step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]
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2026-08-17 Assembly guide: Preparation chapter, Control Board placeholder, build order
    - New OV-CA-AG-00-PREP chapter: workspace/ESD/equipment setup, CAD
    access, parts verification against BOM Tool and PCB Tool, correct-PCB
    check; images borrowed from the IO Board and Gate Driver chapters
    - New OV-CA-AG-03-CB placeholder chapter for the main control board
    - Guide index lists all four chapters and the updated build order;
    nav_order renumbered 131-134
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2026-08-17 Re-export C2-A releases from updated mechanical model (tag bb16303a)
    - Tag C2-A moved to the updated-model commit in the hardware repo
    - Printed-part quantities fixed: DC link spacer x6 and shell x1 now flow
    from new info.txt files (previously defaulted to 1)
    - McMaster 6926K56 qty 3 -> 5 from model merge
    - All board artifacts, mech parts, vendor BOMs, and tool pages
    regenerated
    [Consolidated_BOM.csv, HW-C2-BSP-A.step, HW-C2-CHSP-A.step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]
2026-08-20 STL viewer: dimensions, measure tool, grid, wireframe, reset, screenshot
    Rework the 3D part viewer toolbar: bounding-box W x D x H readout with
    toggleable dimension lines, two-click surface measurement in mm,
    grid/axes and wireframe toggles, view reset, and PNG screenshot.
2026-08-20 HWRelease: export whole-assembly models and support boardless chassis
    fcextract gains export_assembly(): every visible solid in the chassis
    FCStd is exported (placements honored) to Mechanical/assembly.step and
    assembly.stl via headless FreeCAD.
    update() now processes a chassis when it has boards OR mechanical
    content (FCStd / Mechanical/Fab), so mechanical-only chassis like
    Chassis3 produce a CHASSIS-<short>-<tag> manifest entry with mech
    parts and assembly artifacts; tags are only skipped when they contain
    neither boards nor mechanical content. Price estimates are attached
    only when vendor BOMs were actually exported.
    The BOM Tool lists chassis entries with an assembly STL and links to a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
2026-08-20 Remove em dashes across docs and tools
    Replace every U+2014 case-by-case: colons for term-definition lists,
    semicolons/commas/parentheses/sentence splits in prose, ' - ' in
    titles, labels, and CLI/PDF output strings. The regex character class
    in bom_manager/fab.py that must match em dashes is kept.
2026-08-20 STL viewer: fix measure mode, grid orientation, edge-based wireframe
    Measure mode dropped every first click (clearMeasurement raced the
    point store), the grid helper lay in the XZ plane while models are
    Z-up, and material.wireframe rendered every STL triangle. Wireframe is
    now an EdgesGeometry feature-edge overlay; also: left-button-only
    measure clicks, hiDPI pixel ratio, FOV-based camera fit, toolbar
    gated until model load.
2026-08-20 Add vibration test plan (MIL-STD-810H Method 514.8)
    Vibration test plan for the C2 assembly: Category 4 composite
    wheeled-vehicle qualification profile (5-500 Hz, ~2.24 g RMS vertical,
    cited by figure/table, values to be verified against the standard), a
    minimum-integrity screening profile for low-cost rigs, fixturing,
    instrumentation, procedure, acceptance criteria, and HARA /
    fault-injection traceability with the E-01 standards discrepancy
    called out.
2026-08-20 Add thermal test plan with DIY cooler chamber
    Thermal verification plan for the C2 design-doc claims (heatsink
    R_th(s-a), DC-link +40.1 K plate rise, FSR-08 90/105 C thresholds):
    styrofoam-cooler chamber with heater safety layering, probe
    calibration, dummy-load heatsink measurement with an explicit error
    budget, DC-link plate-rise check, telemetry-correlated threshold
    sweeps, and honest limitations.
2026-08-20 Replace hand-rolled STL viewer with embedded Online3DViewer
    Vendor Online3DViewer 0.18.0 (MIT) into Docs/Tools/BOM-Tool/o3dv and
    rewrite stl-viewer.html around OV.EmbeddedViewer, keeping the
    ?file= contract (plus ?files=a,b,c for multi-model) and the OpenVVVF
    header. Drops the CDN dependency for STL/OBJ/3MF/glTF. docgen's
    copy_assets now walks asset subdirectories recursively so the engine
    files reach site/.
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2026-08-20 HWRelease: export assemblies as per-subassembly STEP/STL files
    One monolithic chassis STEP was far too slow (full-doc B-rep export
    including all fastener threads). The assembly export now writes one
    STL+STEP per top-level group/body into Mechanical/Assembly/, with
    loose hardware merged into a Hardware subassembly. STL is written
    before STEP per subassembly, so a timeout keeps completed chunks.
    Manifest artifacts become assembly.stl/step path lists; the BOM Tool
    links a multi-model 3D assembly view via stl-viewer ?files=.
2026-08-20 Revert "HWRelease: export assemblies as per-subassembly STEP/STL files"
    This reverts commit e8069a0bf4a3fc9ae296e228aad540df1666a1c3.
2026-08-20 Revert "STL viewer: drop the feature-parity note overlay"
    This reverts commit 72ab27ff4b52bbb260ef6c3765e05200473e3e1b.
2026-08-20 Revert "HWRelease: tolerate assembly-export timeouts, keep partial STL"
    This reverts commit f8fc19fc7ccf52620e845eda8c835941e37f26d0.
2026-08-20 Revert "Replace hand-rolled STL viewer with embedded Online3DViewer"
    This reverts commit e6fa073e6f9338a7d4f8144c702228869a4dbcfb.
2026-08-20 Revert "HWRelease: export whole-assembly models and support boardless chassis"
    This reverts commit cd2f7e30fab69468163f87a82388d53b6aac19c7.
2026-08-20 Reapply "Replace hand-rolled STL viewer with embedded Online3DViewer"
    This reverts commit 987e9468e6a8b43f753c0406d864655f325258fd.
2026-08-20 Reapply "STL viewer: drop the feature-parity note overlay"
    This reverts commit 24bd69599e4bb74ca8b226e53c4b79ec334daa3d.
2026-08-20 HWRelease: support boardless chassis (mechanical-only exports)
    Re-applies the chassis3 use case without the reverted assembly
    export: a chassis with no KiCad boards still gets a CHASSIS-<short>-<tag>
    manifest entry when it has a Mechanical FCStd or Fab parts, and the
    BOM Tool lists chassis that carry only mech entries. Tags are skipped
    early only when they have neither boards nor mechanical content.
2026-08-20 Data/Releases: export Chassis3 (tag C3-WIP) mechanical parts
    First boardless-chassis export: 8 parts extracted from the Chassis3
    FCStd (DC-link bus bars, frame baseplate, IGBT clamp plate, top
    enclosure, phase busbar), CHASSIS-C3-C3-WIP entry plus per-part mech
    entries. Parts have no info.txt/fab_spec.yaml yet. C2 boards skipped
    as already exported; tool pages regenerated.
    [Consolidated_BOM.csv, HW-C3-DCLBB-CNPL-A.step, HW-C3-DCLBB-CNPL-A.stl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]
2026-08-20 HWRelease: fix render framing, extract part material from FCStd
    Blender preview renders framed by max-axis distance cropped wide
    parts, and Blender's default 100-unit far clip blanked large ones;
    the camera now fits the bounding sphere against the real vertical
    FOV with scaled clip planes.
    extract_parts now reads each labeled body's ShapeMaterial and writes
    material.json per part (groups fall back to a member body's
    material); export_mech_parts records artifacts.material and the BOM
    Tool shows it with priority fab_spec > model material > info.txt.
2026-08-20 Data/Releases: regenerate with fixed render framing and model materials
    Full --force re-export: all part previews re-rendered with the
    bounding-sphere camera fit (no more cropped wide parts), and
    HW-C3-DCLBB-CNPL-A gains its model-assigned material
    (Aluminum-6061-T6) via ShapeMaterial extraction.
    [HW-C2-BSP-A.step, HW-C2-CHSP-A.step, HW-C2-DCLBB-A.step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]
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2026-08-20 Fix test-count arithmetic; flag TARA as work in progress
    The fault-injection plan claimed 92 tests / 84 executable / 101 line
    items; the truth is 80 defined tests (75 executable, 4 conditional,
    1 deferred-equipment) plus 12 deferred E-series stubs = 92 line
    items. Header, executability summary, SG/hazard range prose (H-11/
    SG-11 removed in v5.4), Table 18 ASIL enumeration, and stale Table 9
    / Section 10.x cross-references corrected; HARA Core mirrors fixed.
    TARA is known outdated (missing RTE/Ethernet and calibration attack
    surfaces, dual-MCU assets, 21434 scaffolding): marked placeholder
    with a prominent WIP notice listing the gaps; safety index notes the
    rewrite is planned.
2026-08-20 Test plans: generalize vibration plan, retitle thermal chamber
    Vibration plan v0.3: motorcycle-specific tailoring removed; now a
    platform-general MIL-STD-810H Method 514.8 Category 4 plan with
    installation-tailoring guidance. Thermal plan v1.1: 'DIY' branding
    dropped; the cooler rig is defined plainly by its chamber specs.
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2026-08-20 C2 ratings: 220 A continuous / 600 A 60 s peak, 6 kHz clamp
    Continuous rating derived from constraints at 6 kHz: the DC-link
    plate (90 C FSR-08 derate onset) binds at 220 A RMS, below the
    ~330 A electrolytic ripple limit; stated as a conservative bound
    with the five conservatisms itemized and the two bench measurements
    (can-branch ripple probe, can NTC vs plate model) that would raise
    it. Peak validated as 600 A RMS for 60 s (junction ~101 C vs 125 C
    target; plate reaches 92-97 C, >=8 K below SSO) with a verifiable
    rolling 10-min RMS <= 220 A duty requirement. PWM clamped at 6 kHz
    (8 kHz dropped; near the 7.8 kHz can-branch resonance). Power-Stages
    index, both thermal docs, ripple doc, and t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
2026-08-23 c2 rev B mechanical release + hwrelease mech-only release support
    HWRelease:
    - a chassis-named tag (e.g. C2-B) now pins the chassis release rev and
    scopes the export to that chassis, so mechanical-only change sets can
    move the chassis revision without a board rev bump (previously the
    chassis rev came from board revs and the release would be skipped)
    - regression test for the above; README + HWRelease-System doc updated
    C2 rev B release (from InverterGen5 tag C2-B):
    - CHSP-A -> CHSP-B: heatspreader plate now 6.35 mm (was 3.17), 90 deg
    countersink spec
    - DCLMH-200-PRINTED-A -> -B: captive holder fix, film-cap interference
    resolved
    - DCLSPCR-PRINTED-B: conjoined spacer sets, qty 3 (w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
    [C2-HW-BSP-A.step, Consolidated_BOM.csv, HW-C2-BSP-A.step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]
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2026-08-29 bom-manager: build-variant support + C2 rev C release with 450v build
    - Tools/BOMManager: variants.yaml rules (exclude/add/setqty) applied to
    parsed BOM items; generate builds all declared variants, writes
    Builds/<variant>/, Variant_Comparison.md and variants.json
    - Tools/HWRelease: release exports carry Builds/, comparison report and
    variants manifest; build_variants listed in manifest artifacts
    - Data/Releases: new C2/C chassis export (200v default + 450v build:
    UCS2W680MHD cap swap, DCLMH-450 holder/spacer, 94669A193 standoffs),
    C3-WIP re-exported, C2/A refreshed by the C3-WIP tag's board revs
    - Data/Parts: UCS2W680MHD registered (647-UCS2W680MHD)
    [C2-HW-BSP-A.step, Consolidated_BOM.csv, HW-C2-BSP-A.step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]
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2026-09-05 regenerate release data after DNP grouping fix (hwrelease update --force)
    [Consolidated_BOM.csv, HW-C2-BSP-A.step, HW-C2-CHSP-A.step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]
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2026-09-27 test 24: SG-10 DC-link OV/UV validation (threshold injection, fix-forward warning/derate layers)
    [sg10_critical_ov.csv, sg10_regression.csv]
2026-09-27 test 25: DESAT/FLT protection via 100 V winding pulses; FLT->MCU blindness fixed (checklist SG-12/SG-14)
    [desat_flt_detection.csv, desat_pulses.csv]
